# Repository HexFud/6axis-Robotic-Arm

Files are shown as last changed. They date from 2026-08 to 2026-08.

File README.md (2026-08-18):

## 6 Axis Robotic Arm

I created this 6 axis robotic arm entirely from scratch starting from the PCB to the 3D modelling and designing.

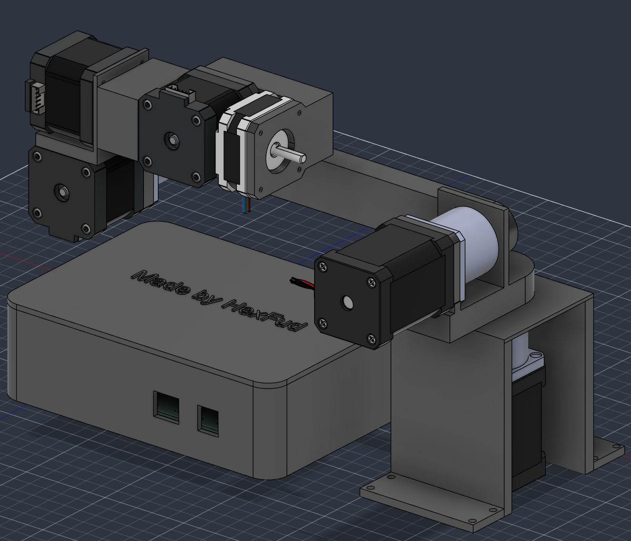
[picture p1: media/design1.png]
design1


## How this was made

I designed the PCB that can take up to 6 motors (I used 6 NEMA 17) with 6 driver boards that you can directly plug into the PCB. In the PCB case there is a cutout for a 40mm fan directly pluggable into the dedicated +5V socket (identified by FAN or J8 connector), this is foundamental to keep the motor drivers cool and keep things as safe as possible. The board runs on 24V connection and includes connections for:

1. **6 limit switches** for homing each joint
2. **A CAN Bus interface**
3. **An emergency stop button socket** for safety reason. 

## External connections breakdown

1. **E-STOP (J21)** The emergency stop circuit is NC so the board without this button won't power on, if you want to avoid this you can short 2 pins of the J21 connector with a jumper (please mind your safety)
2. **CAN Bus (J22)** This is the port to make the PCB comunicate with the PC and it only has 2 pins CAN_H and CAN_L if you want to send commands directly to the board you need to have a USB-CAN adapter
3. **Power button (J19)** The socket on the PCB has 4 pins
 
| Pin | Function | Where to connect |
| :---: | :--- | :--- |
| **1** | `GND` | Switch contact + LED Negative (`-`) wire |
| **2** | `PWR` | Switch contact |
| **3** | `+3V3` | LED Positive (`+`) wire |
| **4** | `Reserved` | *Do not connect any wire to it* |

## Mechanical design and why I chose certain components

To make sure the arm can lift certain payloads wihout struggling I preferred to not use a direct-drive style to move the joints, this is why for the most heavy and tourqe demanding parts I paired the NEMA 17 motors with 20:1 and 10:1 gearboxes (you can see them marked in red)

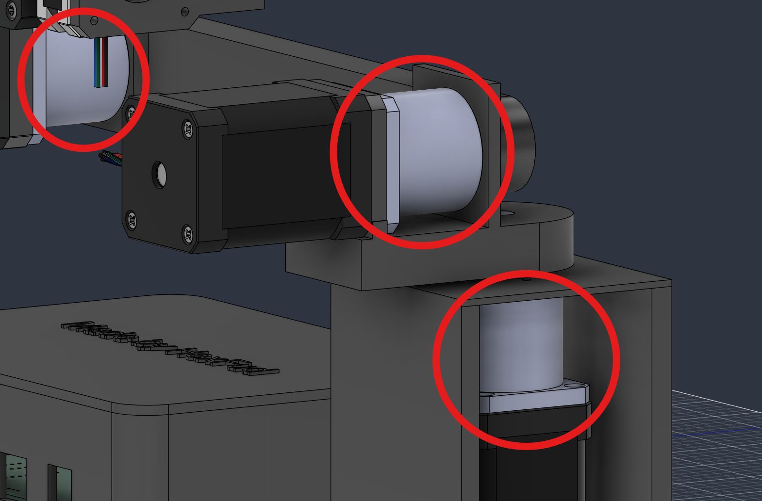
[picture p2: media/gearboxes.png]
gearboxes


## How to flash the firmware

My project doesn't have a USB-C or other type of interfaces so to flash the firmware you need a ST-LINK V2 where you need to wire up the correct cable from the usb to the board (J18 connector) and download the free software [STM32CubeProgrammer](https://www.st.com/content/st_com/en/stm32cubeprogrammer.html) and you simply need to upload the firmware.

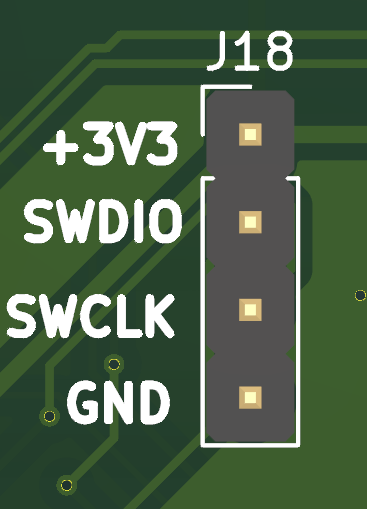
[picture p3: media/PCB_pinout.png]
Connector pinout


Steps to reproduce (note that you need to do both):

In Arduino IDE:
1. Install Arduino IDE
2. Paste https://github.com/stm32duino/BoardManagerFiles/raw/main/package_stmicroelectronics_index.json into prefernces -> additional board manager URL's
3. Search STM32 into the boards stab and install it
4. Go in tools -> board -> STM32 MCU based boards and select Generic STM32F4 series
5. Go in tools -> board part number and select Generic F446RETx
6. Go to sketch -> export compiled binary

In STM32CubeProgrammer:
1. Install the software from the link above
2. Insert the ST-Link V2 USB into the pc
3. Connect the pins explained above (do not connect the 24V power supply, the ST-Link has enough power to power the chip to flash)
4. In STM32CubeProgrammer ensure that ST-LINK is selected and click connect
5. Go in the erasing & programming tab and select the previously exported .bin file
6. Click start programming and if everything went right you'll see Download verified successfully

## Filament reccomendation

Because stepper motors and the drivers generate heat around 50°C-60°C I strongly reccomend to use filaments like PETG, ABS or ASA instead of standard PLA ensuring the plastic won't soften, warp or melt during intensive load.

## ⚠️⚠️ Safety advice ⚠️⚠️

This project includes experimental software, hardware designs, and assembly documentation are still under development and may contain bugs, errors, or incomplete features. By using, building, or modifying this project, you acknowledge that:

1. You use this project entirely at your own risk
2. You are solely responsible for safe assembly, testing, and operation
3. The autor isn't responsible for any type of damage, injury or loss to people or the machine itself

By proceeding, you accept all risks and agree to these conditions. If you do not acknowledge these risks and conditions, please do not use or build this project.

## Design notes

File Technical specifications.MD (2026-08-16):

# Technical Specifications

## 1. Power Supply

| Parameter | Value |
|---|---|
| DC input voltage | 18-28V, 24V DC nominal |
| Standby power consumption (motors energized, holding torque) | 10-15W |
| Standard multi-axis operation power consumption | 100-150W (average) |
| Peak power (simultaneous high-speed acceleration) | ~240W |

## 2. Current Ratings

| Rail / component | Value |
|---|---|
| Main 24V distribution, system peak | up to 8A |
| Each TMC5160 driver, continuous RMS current | 1.8-2.5A per axis |
| Each TMC5160 driver, transient peak burst (with active forced-air cooling) | up to 3.6A |
| 3.3V logic rail, continuous consumption (180MHz core clock) | ~150mA |
| Dedicated 5V rail (cooling fan + auxiliary peripherals) | up to 500mA |

## 3. Thermal Limits

| Parameter | Value |
|---|---|
| Driver silicon pre-warning threshold | 100°C |
| Automatic over-temperature shutdown | 120°C |
| Operating ambient temperature range | 0-45°C |

## 4. Mechanical and Performance

| Parameter | Value |
|---|---|
| Reduction ratio on primary joints | 20:1 |
| Maximum torque (base and shoulder axes) | > 12.8 Nm |
| Maximum recommended payload (at 400mm reach) | 1.5-2.0 kg |
| Maximum joint angular velocity | ~180°/s (30 RPM at gearbox output) |
| Maximum tool tip linear speed | up to 600 mm/s |
| Minimum angular resolution | 0.0056° per microstep |
| Estimated positioning repeatability | 0.1-0.2 mm |

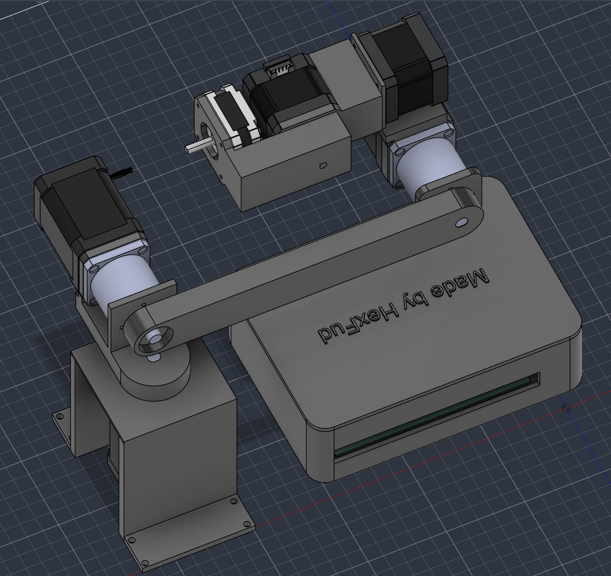
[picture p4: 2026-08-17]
media/design2.png

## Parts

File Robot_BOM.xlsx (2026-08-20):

Reference | Qty | Part | Prezzo unit. (€) | Totale (€) | Link AliExpress | Totale $
U9 | 1 | STM32F446RET6 | €5.00 | €5.00 | https://www.aliexpress.com/item/1005009080237227.html | 5.85
U8 | 1 | AMS1117-3.3 (10pz) | €1.75 | €1.75 | https://www.aliexpress.com/item/33022785837.html | 2.0475
U10 | 1 | SN65HVD230 | €3.80 | €3.80 | https://it.aliexpress.com/item/1005006203720105.html | 4.446
U11 | 1 | PC817 (20pz) | €1.20 | €1.20 | https://www.aliexpress.com/item/1005009954843288.html | 1.404
Q10 | 1 | AO4407A (10pz) | €5.84 | €5.84 | https://www.aliexpress.com/item/1005006303212098.html | 6.8328
D2 | 1 | SMBJ36A (50pz) | €3.50 | €3.50 | https://www.aliexpress.com/item/1005002204221759.html | 4.095
F3 | 1 | PTC 1812 3A 36V (100pz) | €6.70 | €6.70 | https://www.aliexpress.com/item/32834981808.html | 7.839
Y3 | 1 | 8MHz 5032 (10pz) | €2.00 | €2.00 | https://www.aliexpress.com/item/1005008632259152.html | 2.34
J24, J26… | 2 | Header 2x8 F (10pz) | €2.90 | €5.80 | https://www.aliexpress.com/item/32847429443.html | 6.786
J25, J27… | 6 | JST-XH-4P (kit) | €20.19 | €20.19 | https://it.aliexpress.com/item/1005009894347474.html | 23.6223
J2, J8…J12, J20 | 7 | JST-XH-3P (kit) |  |  |  | 0
J21, J22 | 2 | JST-XH-2P (kit) |  |  |  | 0
J19 | 1 | JST-PH-4P (kit) | €9.18 | €9.18 | https://www.aliexpress.com/item/1005010504121398.html | 10.7406
J17 | 1 | 2 pin screw terminals 5mm (100pz) | €10.42 | €10.42 | https://www.aliexpress.com/item/1005011820630047.html | 12.1914
J18 | 1 | Header 4 pins (20pz) | €2.05 | €2.05 | https://www.aliexpress.com/item/1005007093958549.html | 2.3985
C18, C20… | 6 | 100µF 35V (40pz) | €2.00 | €2.00 | https://it.aliexpress.com/item/1005011811368397.html | 2.34
C15, C16 | 2 | 10µF 0805 (smd) | €2.00 | €2.00 | https://it.aliexpress.com/item/1005012364450156.html | 2.34
C12 | 1 | 4.7µF 0805 (smd) | €2.00 | €2.00 |  | 2.34
C6..C14, C17… | 14 | 100nF 50V 0805 (smd) | €4.50 | €4.50 | https://it.aliexpress.com/item/1005010243722146.html | 5.265
C1, C2 | 2 | 18pF 50V 0805 (smd) | €5.00 | €5.00 |  | 5.85
R4, R8, R9..R21 | 12 | 10k 0805 (book) | €40.00 | €40.00 | https://it.aliexpress.com/item/1005005504891922.html | 46.8
R7, R10 | 2 | 100k 0805 (book) |  |  |  | 0
R18 | 1 | 2.2k 0805 (book) |  |  |  | 0
R5, R6 | 2 | 1k 0805 (book) |  |  |  | 0
R20 | 1 | 120R 0805 (book) |  |  |  | 0
D4, D5 | 2 | LED 0805 (100pz) BUY RED AND BLUE !!! | €1.00 | €2.00 | https://it.aliexpress.com/item/1005012857004893.html | 2.34
SW2 | 1 | Tactile 6x6 (50pz) | €2.91 | €2.91 | https://it.aliexpress.com/item/32815937778.html | 3.4047
M1, M2 | 2 | NEMA 17 60mm | €18.00 | €36.00 | https://it.aliexpress.com/item/1005008385016960.html | 42.12
M3, M4, M5 | 3 | NEMA 17 40mm | €9.00 | €27.00 | https://it.aliexpress.com/item/1005008459399126.html | 31.59
M6 | 1 | NEMA 17 20mm | €12.00 | €12.00 | https://it.aliexpress.com/item/1005010167230439.html | 14.04
DRV1..DRV6 | 6 | TMC2130 SPI | €7.30 | €44.00 | https://it.aliexpress.com/item/1005004590796152.html | 51.48
PSU1 | 1 | MeanWell LRS-200-24 | €21.00 | €21.00 | https://it.aliexpress.com/item/1005006917685323.html | 24.57
FAN1 | 1 | Noctua NF-A4x20 5V | €40.00 | €40.00 | https://www.aliexpress.com/item/1005001936967690.html | 46.8
ESTOP1 | 1 | E-STOP 22mm NC | €5.00 | €5.00 | https://it.aliexpress.com/item/1005008518428843.html | 5.85
BTN1 | 1 | 12mm LED button 6V | €2.00 | €2.00 | https://it.aliexpress.com/item/1005007274034264.html | 2.34
PRG1 | 1 | ST-Link V2 | €2.50 | €2.50 | https://it.aliexpress.com/item/1005009955503752.html | 2.925
 | 2 | Nema 17 20:1 gearbox | €20.00 | €40.00 | https://it.aliexpress.com/item/1005010354201440.html | 46.8
 | 1 | Nema 17 10:1 gearbox | €18.00 | €18.00 |  | 21.06
 | 2 | 1kg PETG | €25.00 | €50.00 |  | 58.5
 | 1 | PCB board | €100.00 | €100.00 |  | 117
TOTALE | 97 |  |  | €523.59 |  | $612.60

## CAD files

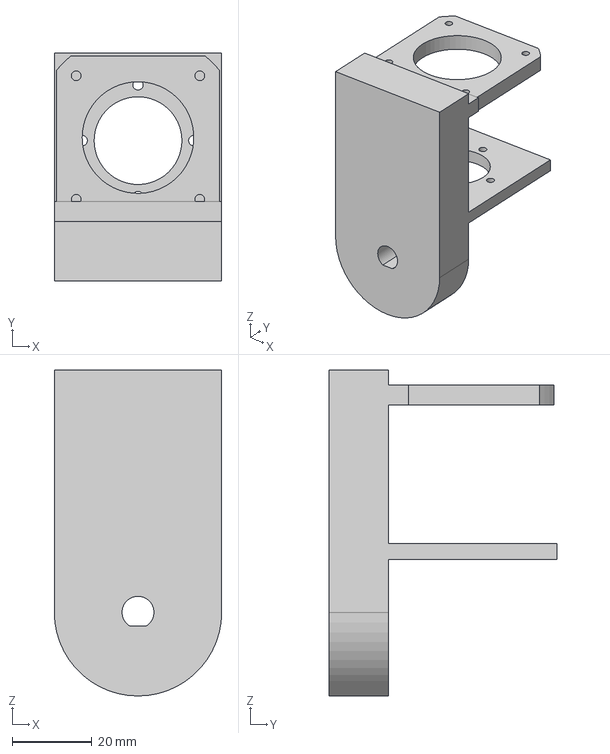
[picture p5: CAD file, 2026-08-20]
production/Arm_1.step
42.0 x 57.2 x 81.8 mm

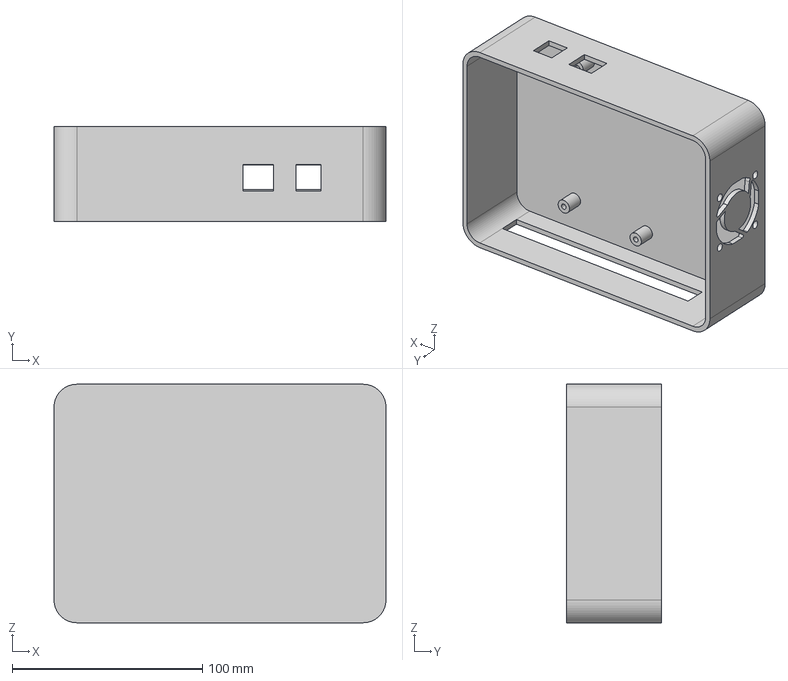
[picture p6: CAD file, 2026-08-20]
production/Arm_Case.step
174.4 x 50.0 x 125.3 mm

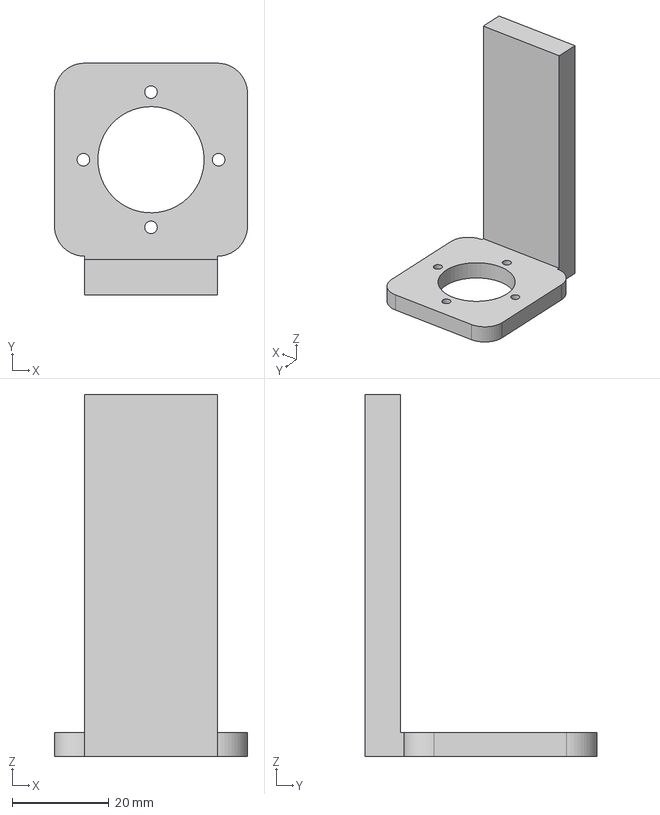
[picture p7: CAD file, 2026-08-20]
production/Arm_3.step
40.0 x 48.0 x 75.0 mm

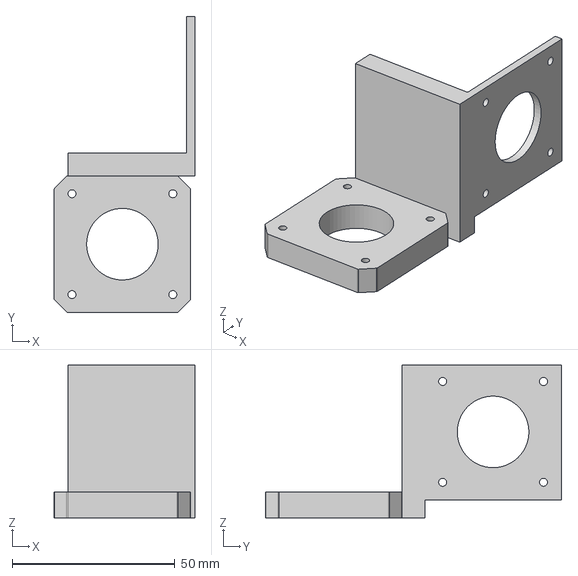
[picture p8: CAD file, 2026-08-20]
production/Arm_4.step
43.3 x 91.0 x 47.0 mm

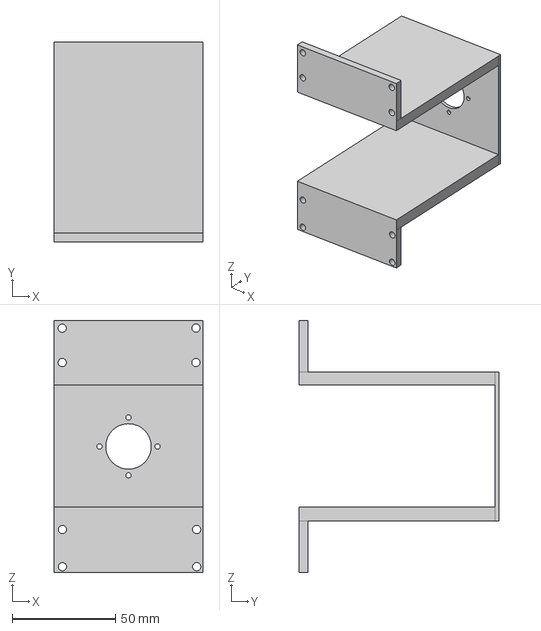
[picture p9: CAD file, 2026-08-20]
production/Arm_Base.step
72.0 x 97.0 x 122.0 mm

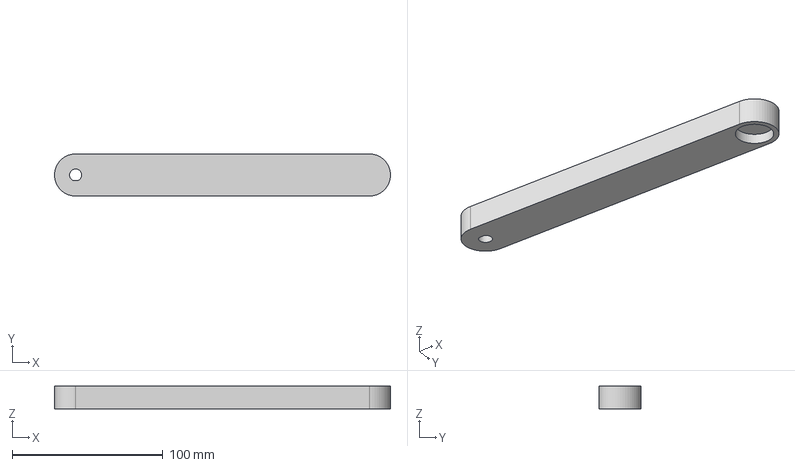
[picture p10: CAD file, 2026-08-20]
production/Arm_2.step
223.0 x 28.0 x 15.0 mm

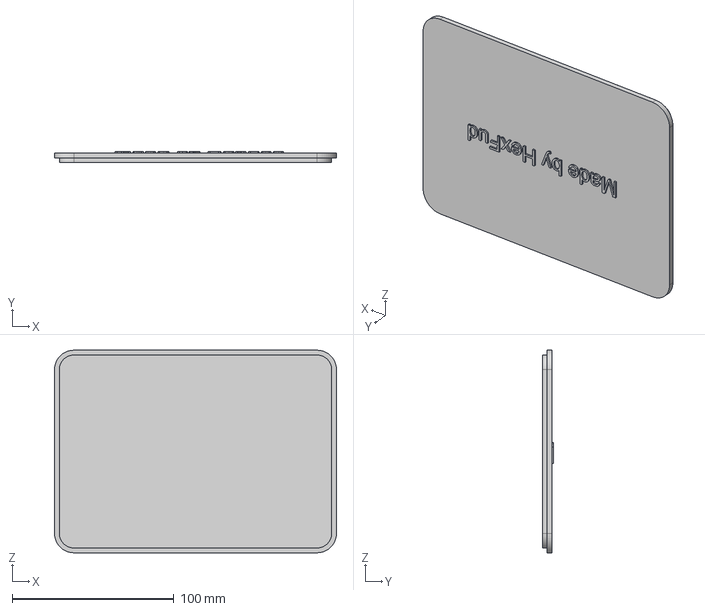
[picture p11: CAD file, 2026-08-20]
production/Case_lid.step
174.4 x 7.00 x 125.3 mm

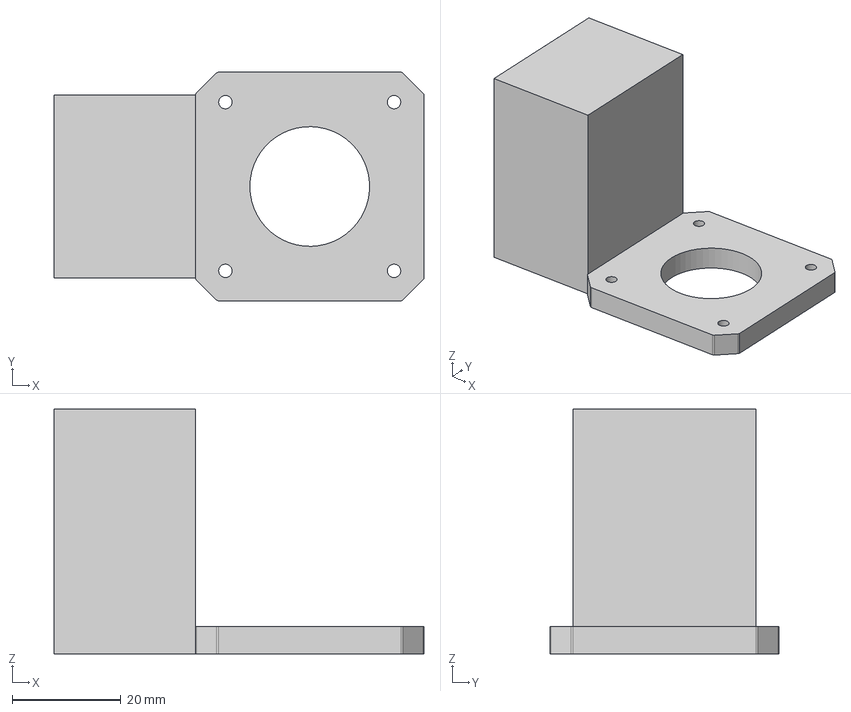
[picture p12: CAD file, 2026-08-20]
production/Arm_5.step
68.0 x 42.0 x 45.0 mm

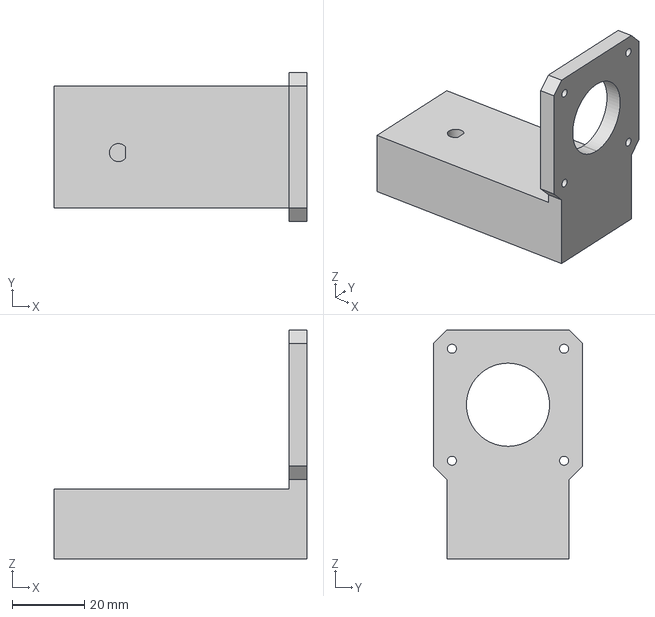
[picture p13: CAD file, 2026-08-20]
production/Arm_6.step
70.0 x 41.3 x 63.3 mm

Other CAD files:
CAD/Complete_arm.stl

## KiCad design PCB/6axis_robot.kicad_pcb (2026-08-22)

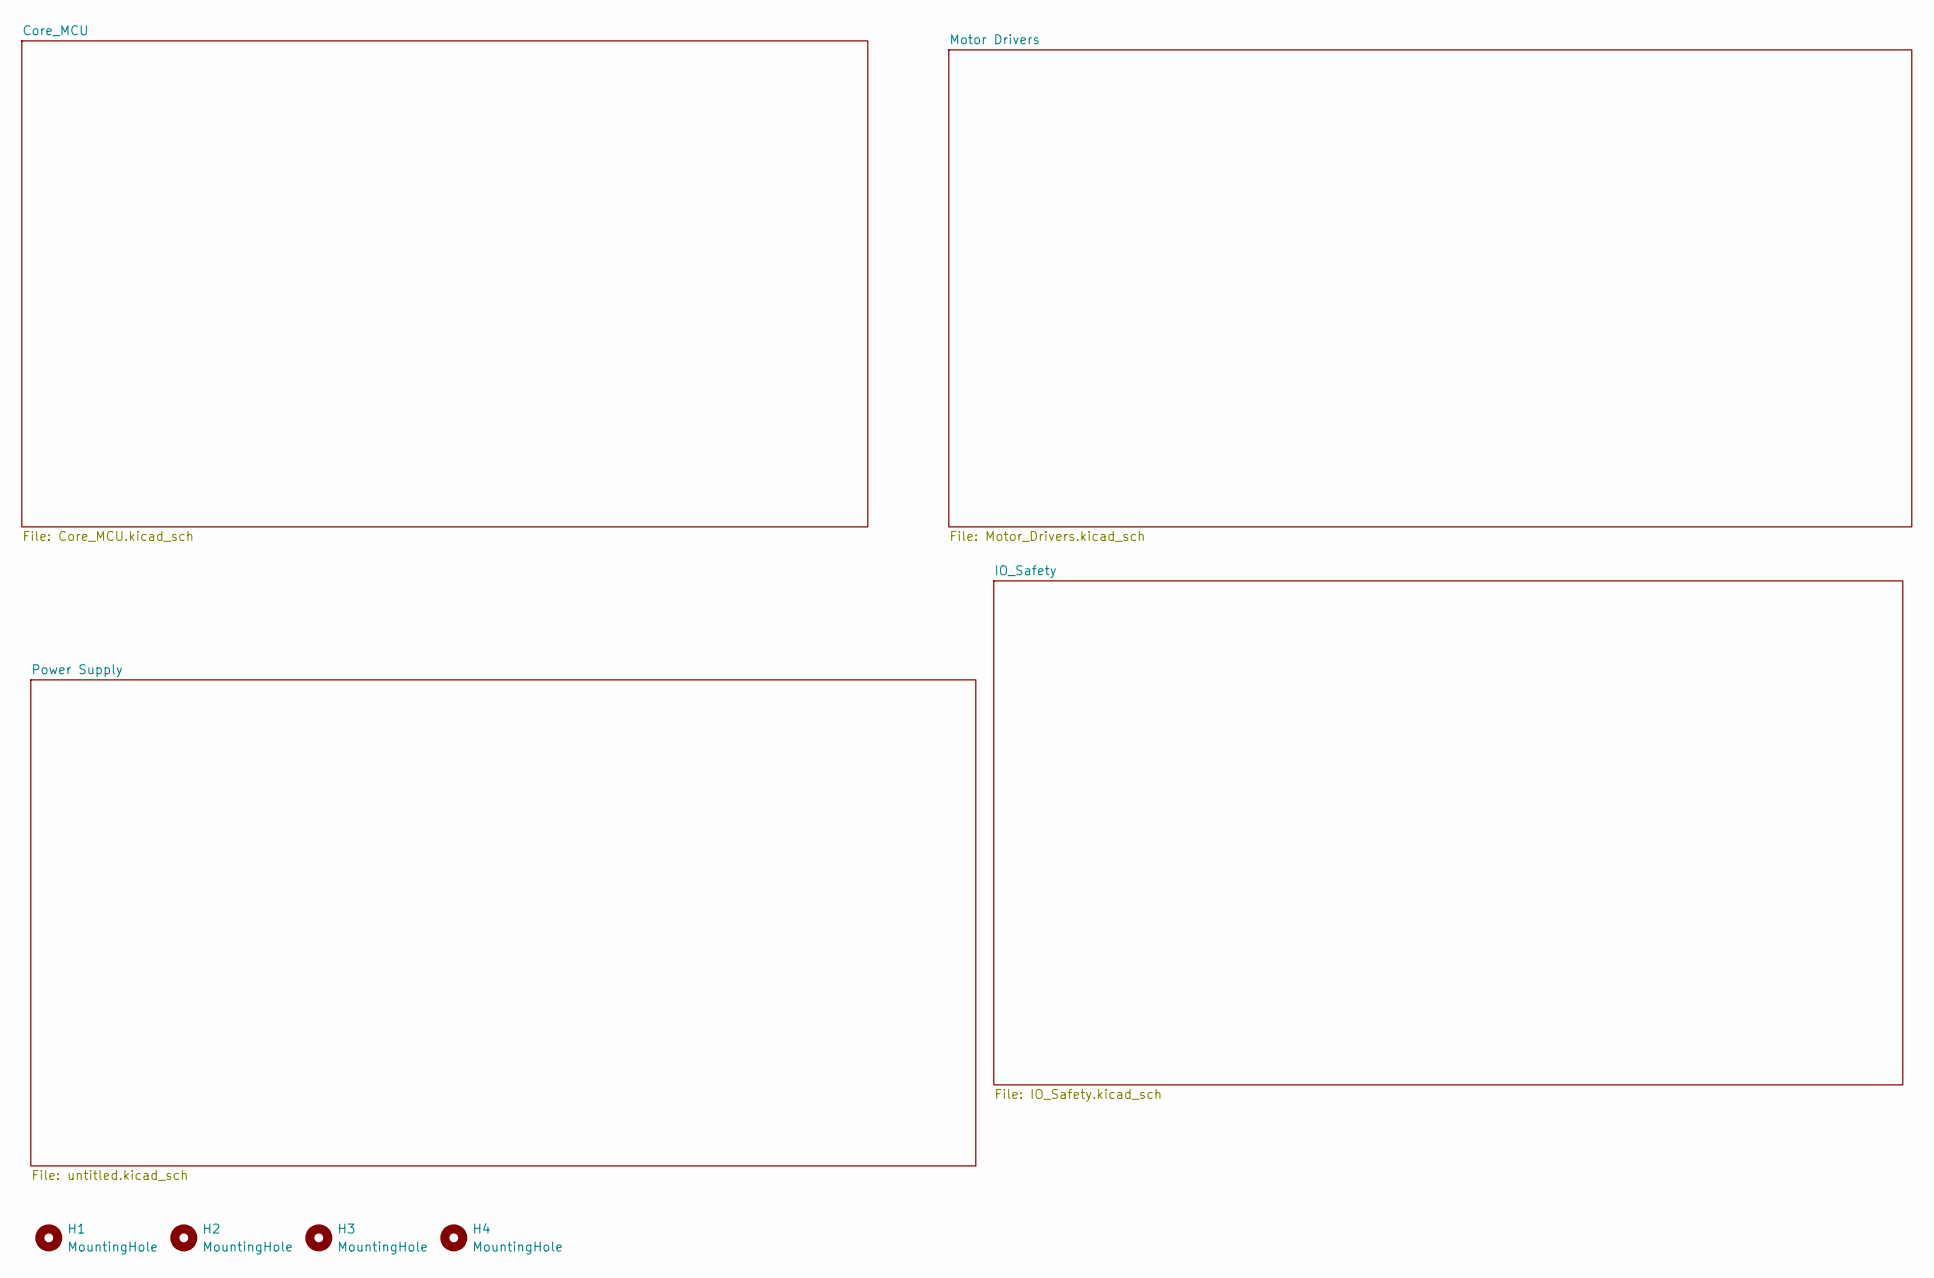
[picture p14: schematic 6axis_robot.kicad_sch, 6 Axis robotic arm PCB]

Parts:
H1, H2, H3, H4: MountingHole; MountingHole_3.2mm_M3

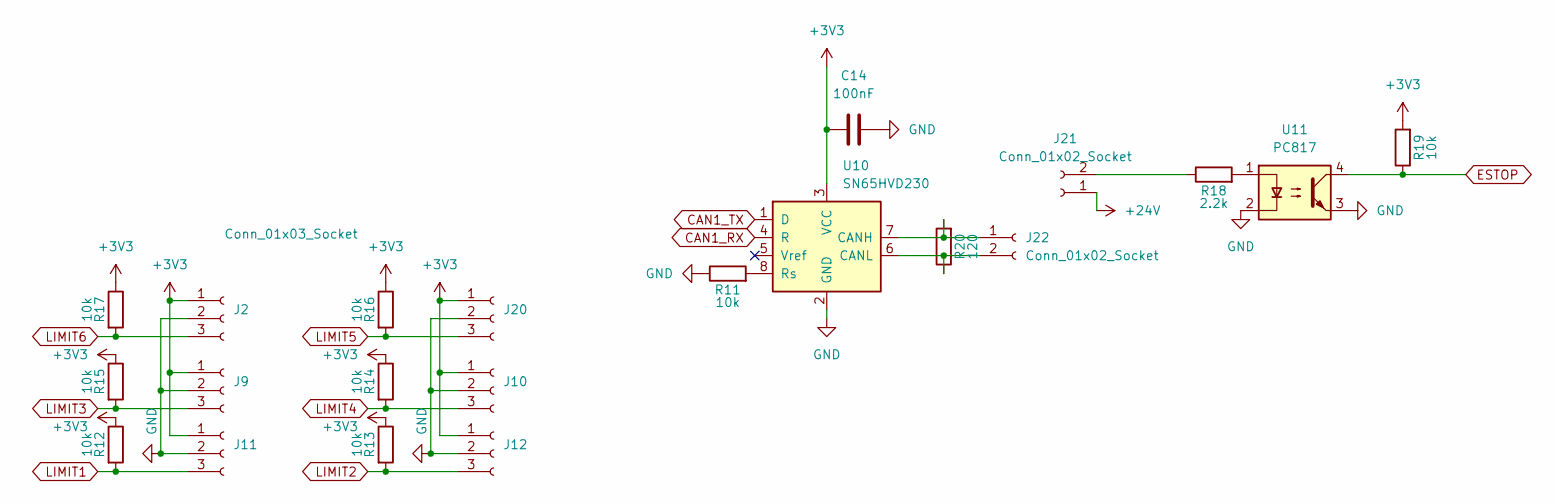
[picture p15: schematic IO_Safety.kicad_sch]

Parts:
C14: 100nF; C_0805_2012Metric
J2, J9, J10, J11, J12, J20: Conn_01x03_Socket; JST_XH_B3B-XH-A_1x03_P2.50mm_Vertical
J21, J22: Conn_01x02_Socket; JST_XH_B2B-XH-A_1x02_P2.50mm_Vertical
R11, R12, R13, R14, R15, R16, R17, R19: 10k; R_0805_2012Metric
R18: 2.2k; R_0805_2012Metric
R20: 120; R_0805_2012Metric
U10: SN65HVD230; SOIC-8_3.9x4.9mm_P1.27mm
U11: PC817; DIP-4_W7.62mm

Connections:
+3V3: C14.1, J2.1, J9.1, J10.1, J11.1, J12.1, J20.1, R12.1, R13.1, R14.1, R15.1, R16.1, R17.1, R19.2, U10.3 (VCC); also elsewhere on the board
+24V: J21.1; also elsewhere on the board
CAN1_RX: U10.4 (R); also elsewhere on the board
CAN1_TX: U10.1 (D); also elsewhere on the board
ESTOP: R19.1, U11.4; also elsewhere on the board
GND: C14.2, J2.2, J9.2, J10.2, J11.2, J12.2, J20.2, R11.1, U10.2 (GND), U11.2, U11.3; also elsewhere on the board
LIMIT1: J11.3, R12.2; also elsewhere on the board
LIMIT2: J12.3, R13.2; also elsewhere on the board
LIMIT3: J9.3, R15.2; also elsewhere on the board
LIMIT4: J10.3, R14.2; also elsewhere on the board
LIMIT5: J20.3, R16.2; also elsewhere on the board
LIMIT6: J2.3, R17.2; also elsewhere on the board
unnamed: J21.2, R18.1
unnamed: J22.1, R20.2, U10.7 (CANH)
unnamed: J22.2, R20.1, U10.6 (CANL)
unnamed: R18.2, U11.1
unnamed: R11.2, U10.8 (Rs)

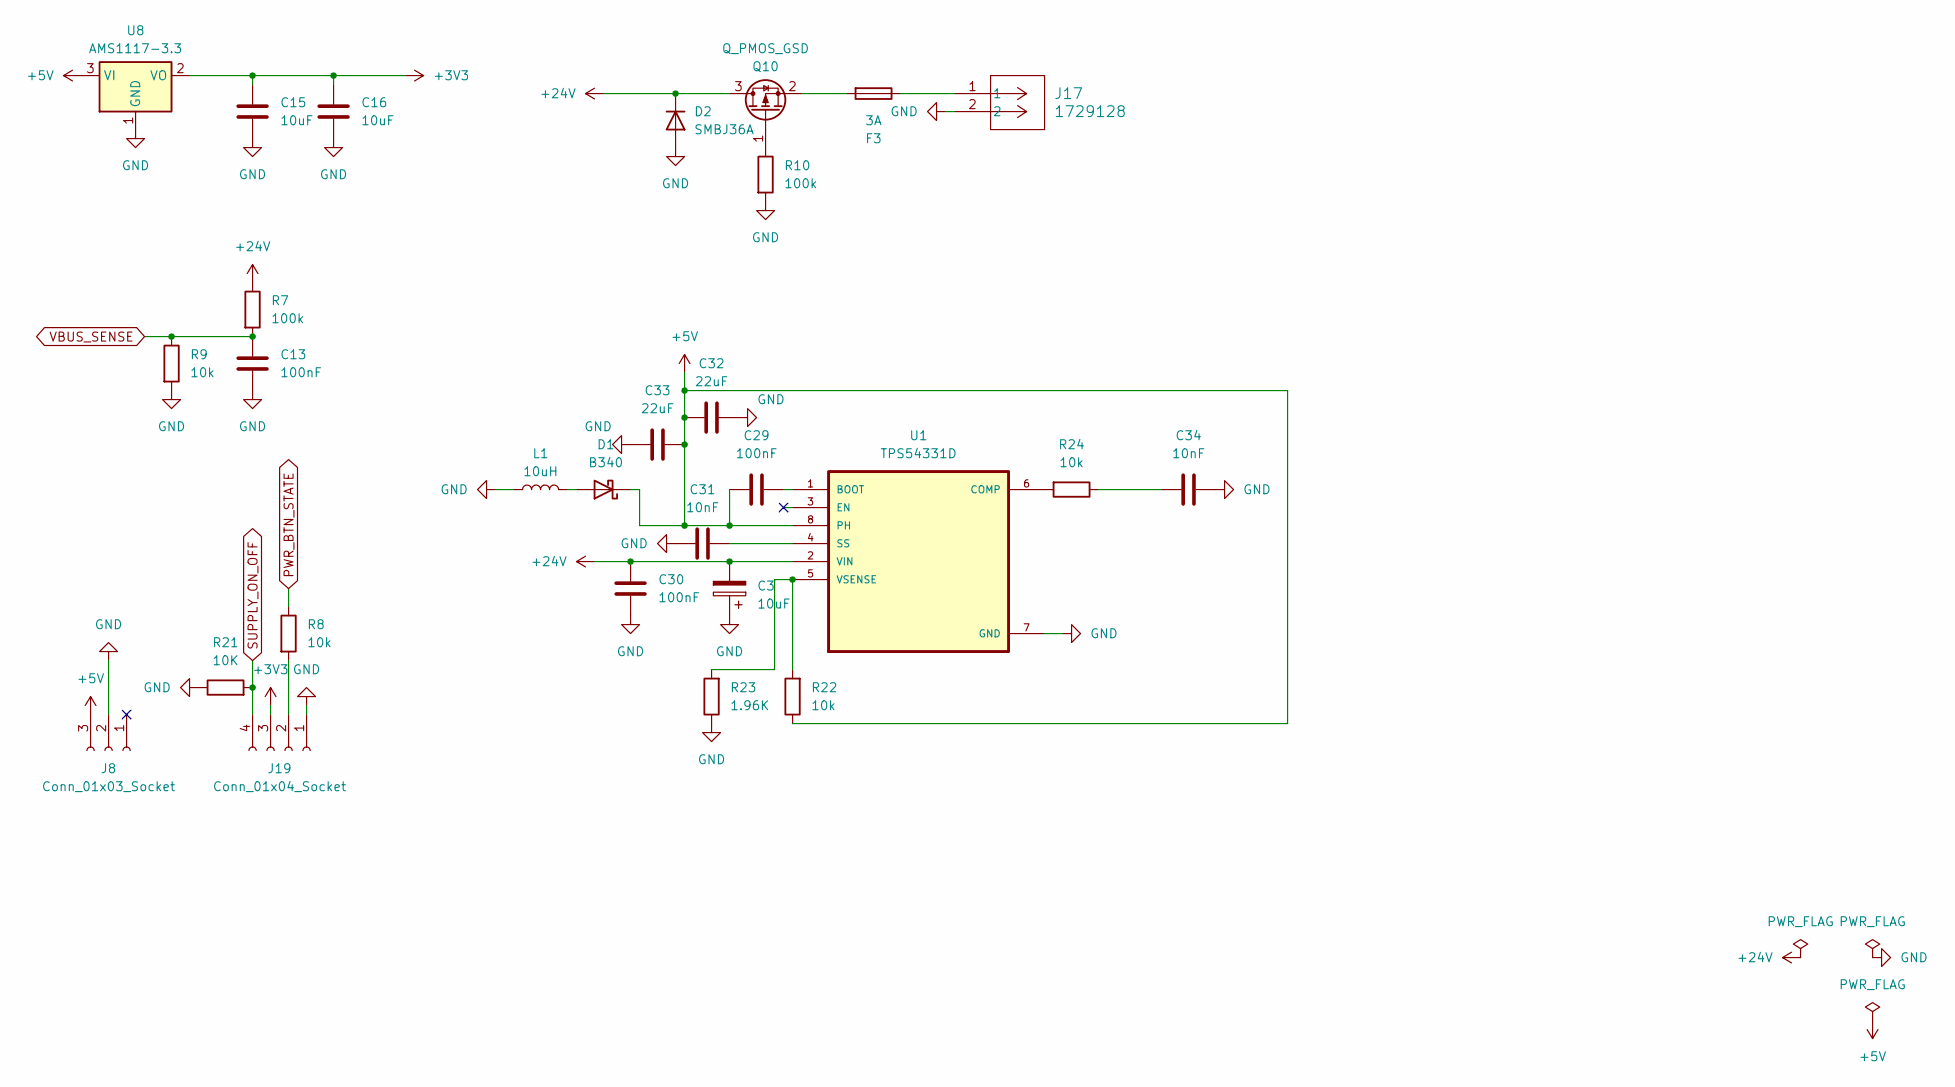
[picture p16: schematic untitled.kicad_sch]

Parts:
C3: 10uF; CP_Radial_D6.3mm_P2.50mm
C13, C29, C30: 100nF; C_0805_2012Metric
C15, C16: 10uF; C_0805_2012Metric
C31, C34: 10nF; C_0805_2012Metric
C32, C33: 22uF; C_0805_2012Metric
D1: B340; D_SMC
D2: SMBJ36A; D_SMB
F3: 3A; Fuse_1812_4532Metric
J8: Conn_01x03_Socket; JST_XH_B3B-XH-A_1x03_P2.50mm_Vertical
J17: 1729128; CONN_1729128_PXC
J19: Conn_01x04_Socket; JST_PH_B4B-PH-K_1x04_P2.00mm_Vertical
L1: 10uH; L_Sunlord_SWPA6045S
Q10: Q_PMOS_GSD; SOT-23
R7, R10: 100k; R_0805_2012Metric
R8, R9, R22, R24: 10k; R_0805_2012Metric
R21: 10K; R_0805_2012Metric
R23: 1.96K; R_0805_2012Metric
U1: TPS54331D; SOIC127P599X175-8N
U8: AMS1117-3.3; SOT-223-3_TabPin2

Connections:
+3V3: C15.2, C16.2, J19.3, U8.2 (VO); also elsewhere on the board
+5V: C29.1, C32.1, C33.2, D1.1 (K), J8.3, R22.1, U1.8 (PH), U8.3 (VI)
+24V: C3.2, C30.1, D2.1 (K), Q10.3 (D), R7.1, U1.2 (VIN); also elsewhere on the board
GND: C3.1, C13.2, C15.1, C16.1, C30.2, C31.1, C32.2, C33.1, C34.2, D2.2 (A), J8.2, J17.2, J19.1, L1.1, R9.2, R10.2, R21.1, R23.1, U1.7 (GND), U8.1 (GND); also elsewhere on the board
unnamed: C34.1, R24.1
unnamed: D1.2 (A), L1.2
unnamed: F3.1, J17.1
unnamed: J19.2, R8.2
unnamed: Q10.1 (G), R10.1
unnamed: F3.2, Q10.2 (S)
unnamed: C29.2, U1.1 (BOOT)
unnamed: R24.2, U1.6 (COMP)
unnamed: C31.2, U1.4 (SS)
unnamed: R22.2, R23.2, U1.5 (VSENSE)
PWR_BTN_STATE: R8.1; also elsewhere on the board
SUPPLY_ON_OFF: J19.4, R21.2; also elsewhere on the board
VBUS_SENSE: C13.1, R7.2, R9.1; also elsewhere on the board

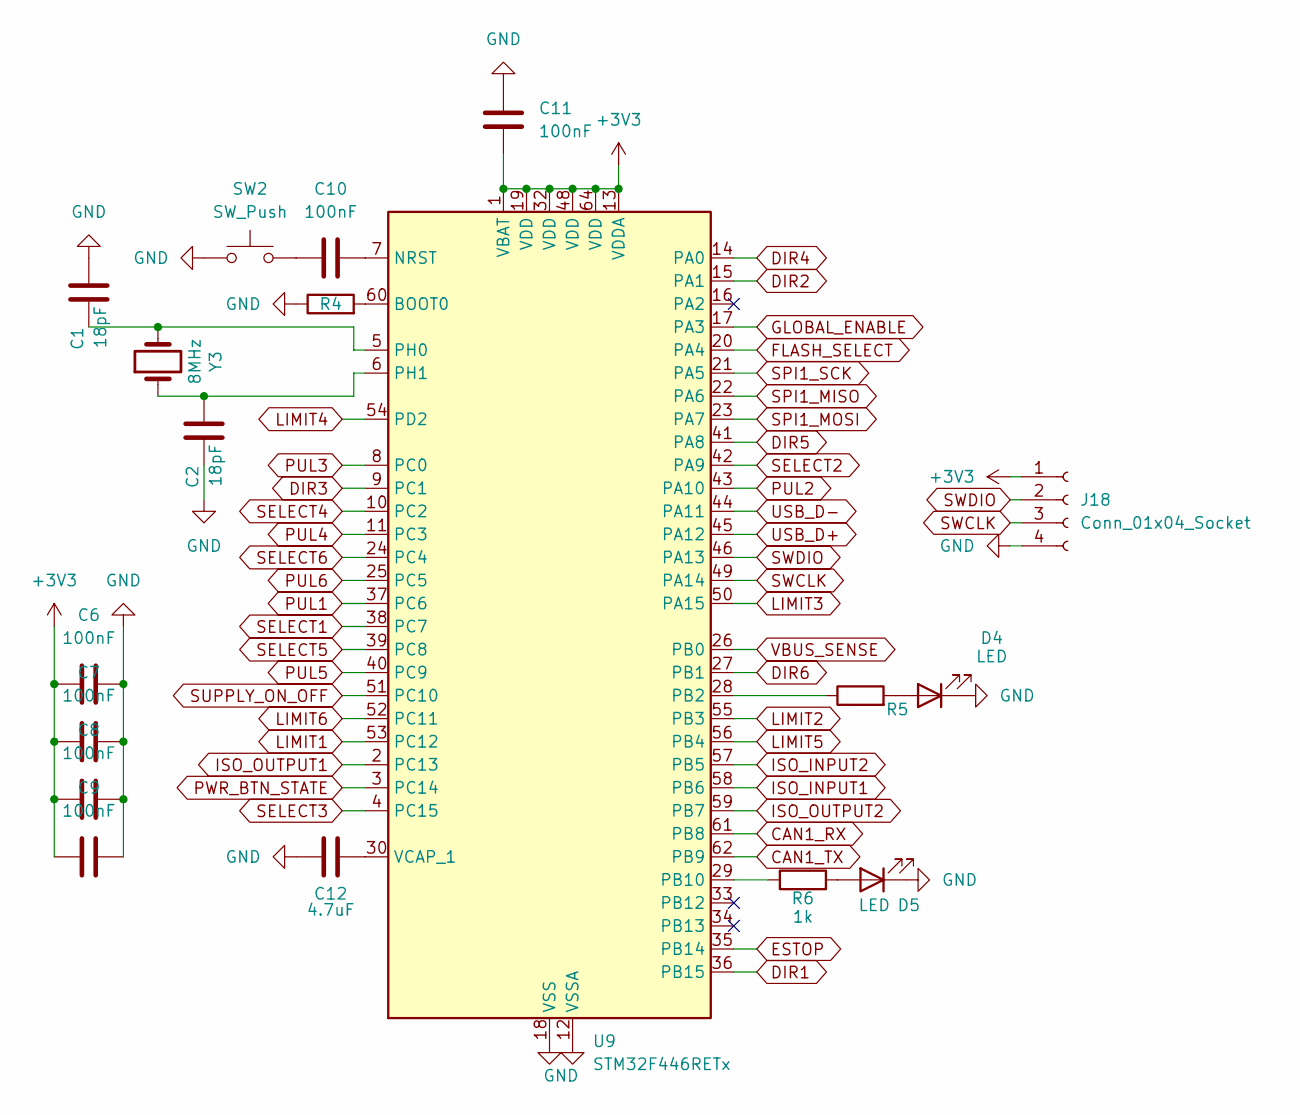
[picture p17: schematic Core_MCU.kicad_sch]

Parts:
C1, C2: 18pF; C_0805_2012Metric
C6, C7, C8, C9, C10, C11: 100nF; C_0805_2012Metric
C12: 4.7uF; C_0805_2012Metric
D4, D5: LED; LED_0805_2012Metric
J18: Conn_01x04_Socket; PinHeader_1x04_P2.54mm_Vertical
R4: 10k; R_0805_2012Metric
R5, R6: 1k; R_0805_2012Metric
SW2: SW_Push; SW_PUSH_6mm
U9: STM32F446RETx; LQFP-64_10x10mm_P0.5mm
Y3: 8MHz; Crystal_SMD_5032-2Pin_5.0x3.2mm

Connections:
+3V3: C6.2, C7.2, C8.2, C9.2, C11.2, J18.1, U9.1 (VBAT), U9.13 (VDDA), U9.19 (VDD), U9.32 (VDD), U9.48 (VDD), U9.64 (VDD); also elsewhere on the board
CAN1_RX: U9.61 (PB8); also elsewhere on the board
CAN1_TX: U9.62 (PB9); also elsewhere on the board
DIR1: U9.36 (PB15); also elsewhere on the board
DIR2: U9.15 (PA1); also elsewhere on the board
DIR3: U9.9 (PC1); also elsewhere on the board
DIR4: U9.14 (PA0); also elsewhere on the board
DIR5: U9.41 (PA8); also elsewhere on the board
DIR6: U9.27 (PB1); also elsewhere on the board
ESTOP: U9.35 (PB14); also elsewhere on the board
FLASH_SELECT: U9.20 (PA4)
GLOBAL_ENABLE: U9.17 (PA3); also elsewhere on the board
GND: C1.2, C2.1, C6.1, C7.1, C8.1, C9.1, C11.1, C12.1, D4.1 (K), D5.1 (K), J18.4, R4.1, SW2.1, U9.12 (VSSA), U9.18 (VSS), U9.31 (VSS), U9.47 (VSS), U9.63 (VSS); also elsewhere on the board
ISO_INPUT1: U9.58 (PB6)
ISO_INPUT2: U9.57 (PB5)
ISO_OUTPUT1: U9.2 (PC13)
ISO_OUTPUT2: U9.59 (PB7)
LIMIT1: U9.53 (PC12); also elsewhere on the board
LIMIT2: U9.55 (PB3); also elsewhere on the board
LIMIT3: U9.50 (PA15); also elsewhere on the board
LIMIT4: U9.54 (PD2); also elsewhere on the board
LIMIT5: U9.56 (PB4); also elsewhere on the board
LIMIT6: U9.52 (PC11); also elsewhere on the board
unnamed: C10.2, SW2.2
unnamed: D4.2 (A), R5.2
unnamed: D5.2 (A), R6.2
unnamed: R4.2, U9.60 (BOOT0)
unnamed: C10.1, U9.7 (NRST)
unnamed: R5.1, U9.28 (PB2)
unnamed: R6.1, U9.29 (PB10)
unnamed: C1.1, U9.5 (PH0), Y3.2
unnamed: C2.2, U9.6 (PH1), Y3.1
unnamed: C12.2, U9.30 (VCAP_1)
PUL1: U9.37 (PC6); also elsewhere on the board
PUL2: U9.43 (PA10); also elsewhere on the board
PUL3: U9.8 (PC0); also elsewhere on the board
PUL4: U9.11 (PC3); also elsewhere on the board
PUL5: U9.40 (PC9); also elsewhere on the board
PUL6: U9.25 (PC5); also elsewhere on the board
PWR_BTN_STATE: U9.3 (PC14); also elsewhere on the board
SELECT1: U9.38 (PC7); also elsewhere on the board
SELECT2: U9.42 (PA9); also elsewhere on the board
SELECT3: U9.4 (PC15); also elsewhere on the board
SELECT4: U9.10 (PC2); also elsewhere on the board
SELECT5: U9.39 (PC8); also elsewhere on the board
SELECT6: U9.24 (PC4); also elsewhere on the board
SPI1_MISO: U9.22 (PA6); also elsewhere on the board
SPI1_MOSI: U9.23 (PA7); also elsewhere on the board
SPI1_SCK: U9.21 (PA5); also elsewhere on the board
SUPPLY_ON_OFF: U9.51 (PC10); also elsewhere on the board
SWCLK: J18.3, U9.49 (PA14)
SWDIO: J18.2, U9.46 (PA13)
USB_D+: U9.45 (PA12)
USB_D-: U9.44 (PA11)
VBUS_SENSE: U9.26 (PB0); also elsewhere on the board

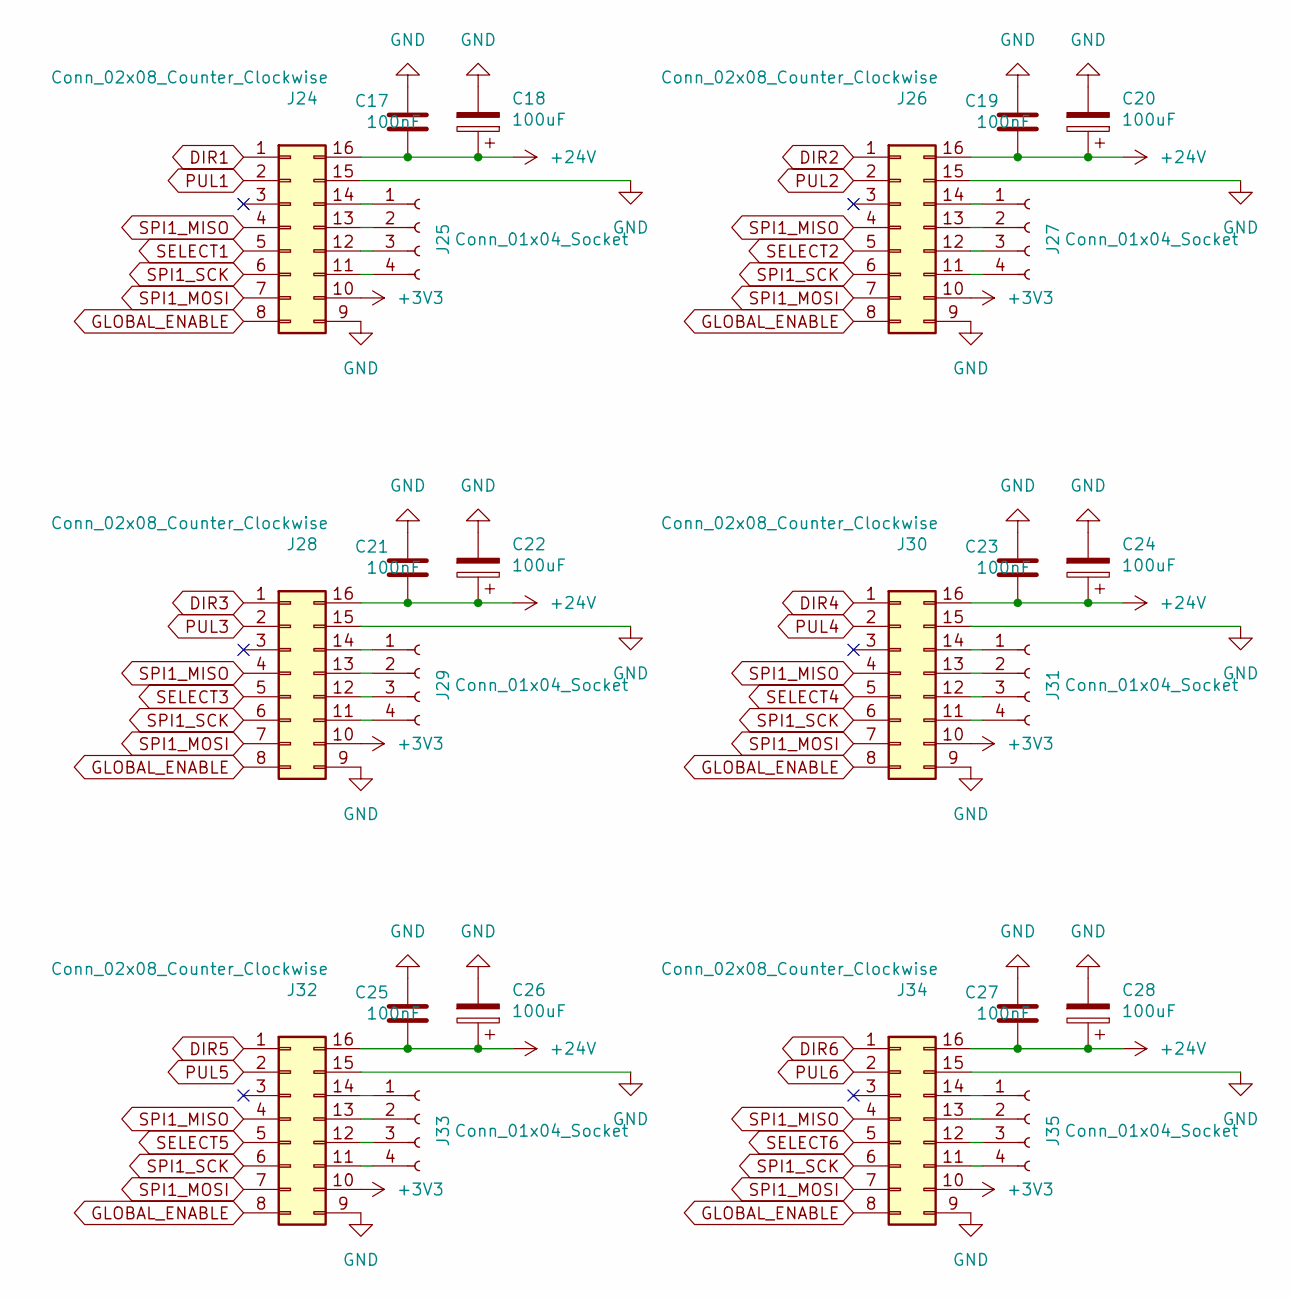
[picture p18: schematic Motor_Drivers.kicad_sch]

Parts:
C17, C19, C21, C23, C25, C27: 100nF; C_0805_2012Metric
C18, C20, C22, C24, C26, C28: 100uF; CP_Radial_D6.3mm_P2.50mm
J24, J26, J28, J30, J32, J34: Conn_02x08_Counter_Clockwise; 8825
J25, J27, J29, J31, J33, J35: Conn_01x04_Socket; JST_XH_B4B-XH-A_1x04_P2.50mm_Vertical

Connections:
+3V3: J24.10, J26.10, J28.10, J30.10, J32.10, J34.10; also elsewhere on the board
+24V: C17.2, C18.1, C19.2, C20.1, C21.2, C22.1, C23.2, C24.1, C25.2, C26.1, C27.2, C28.1, J24.16, J26.16, J28.16, J30.16, J32.16, J34.16; also elsewhere on the board
DIR1: J24.1; also elsewhere on the board
DIR2: J26.1; also elsewhere on the board
DIR3: J28.1; also elsewhere on the board
DIR4: J30.1; also elsewhere on the board
DIR5: J32.1; also elsewhere on the board
DIR6: J34.1; also elsewhere on the board
GLOBAL_ENABLE: J24.8, J26.8, J28.8, J30.8, J32.8, J34.8; also elsewhere on the board
GND: C17.1, C18.2, C19.1, C20.2, C21.1, C22.2, C23.1, C24.2, C25.1, C26.2, C27.1, C28.2, J24.9, J24.15, J26.9, J26.15, J28.9, J28.15, J30.9, J30.15, J32.9, J32.15, J34.9, J34.15; also elsewhere on the board
unnamed: J24.11, J25.4
unnamed: J24.12, J25.3
unnamed: J24.13, J25.2
unnamed: J24.14, J25.1
unnamed: J26.11, J27.4
unnamed: J26.12, J27.3
unnamed: J26.13, J27.2
unnamed: J26.14, J27.1
unnamed: J28.11, J29.4
unnamed: J28.12, J29.3
unnamed: J28.13, J29.2
unnamed: J28.14, J29.1
unnamed: J30.11, J31.4
unnamed: J30.12, J31.3
unnamed: J30.13, J31.2
unnamed: J30.14, J31.1
unnamed: J32.11, J33.4
unnamed: J32.12, J33.3
unnamed: J32.13, J33.2
unnamed: J32.14, J33.1
unnamed: J34.11, J35.4
unnamed: J34.12, J35.3
unnamed: J34.13, J35.2
unnamed: J34.14, J35.1
PUL1: J24.2; also elsewhere on the board
PUL2: J26.2; also elsewhere on the board
PUL3: J28.2; also elsewhere on the board
PUL4: J30.2; also elsewhere on the board
PUL5: J32.2; also elsewhere on the board
PUL6: J34.2; also elsewhere on the board
SELECT1: J24.5; also elsewhere on the board
SELECT2: J26.5; also elsewhere on the board
SELECT3: J28.5; also elsewhere on the board
SELECT4: J30.5; also elsewhere on the board
SELECT5: J32.5; also elsewhere on the board
SELECT6: J34.5; also elsewhere on the board
SPI1_MISO: J24.4, J26.4, J28.4, J30.4, J32.4, J34.4; also elsewhere on the board
SPI1_MOSI: J24.7, J26.7, J28.7, J30.7, J32.7, J34.7; also elsewhere on the board
SPI1_SCK: J24.6, J26.6, J28.6, J30.6, J32.6, J34.6; also elsewhere on the board

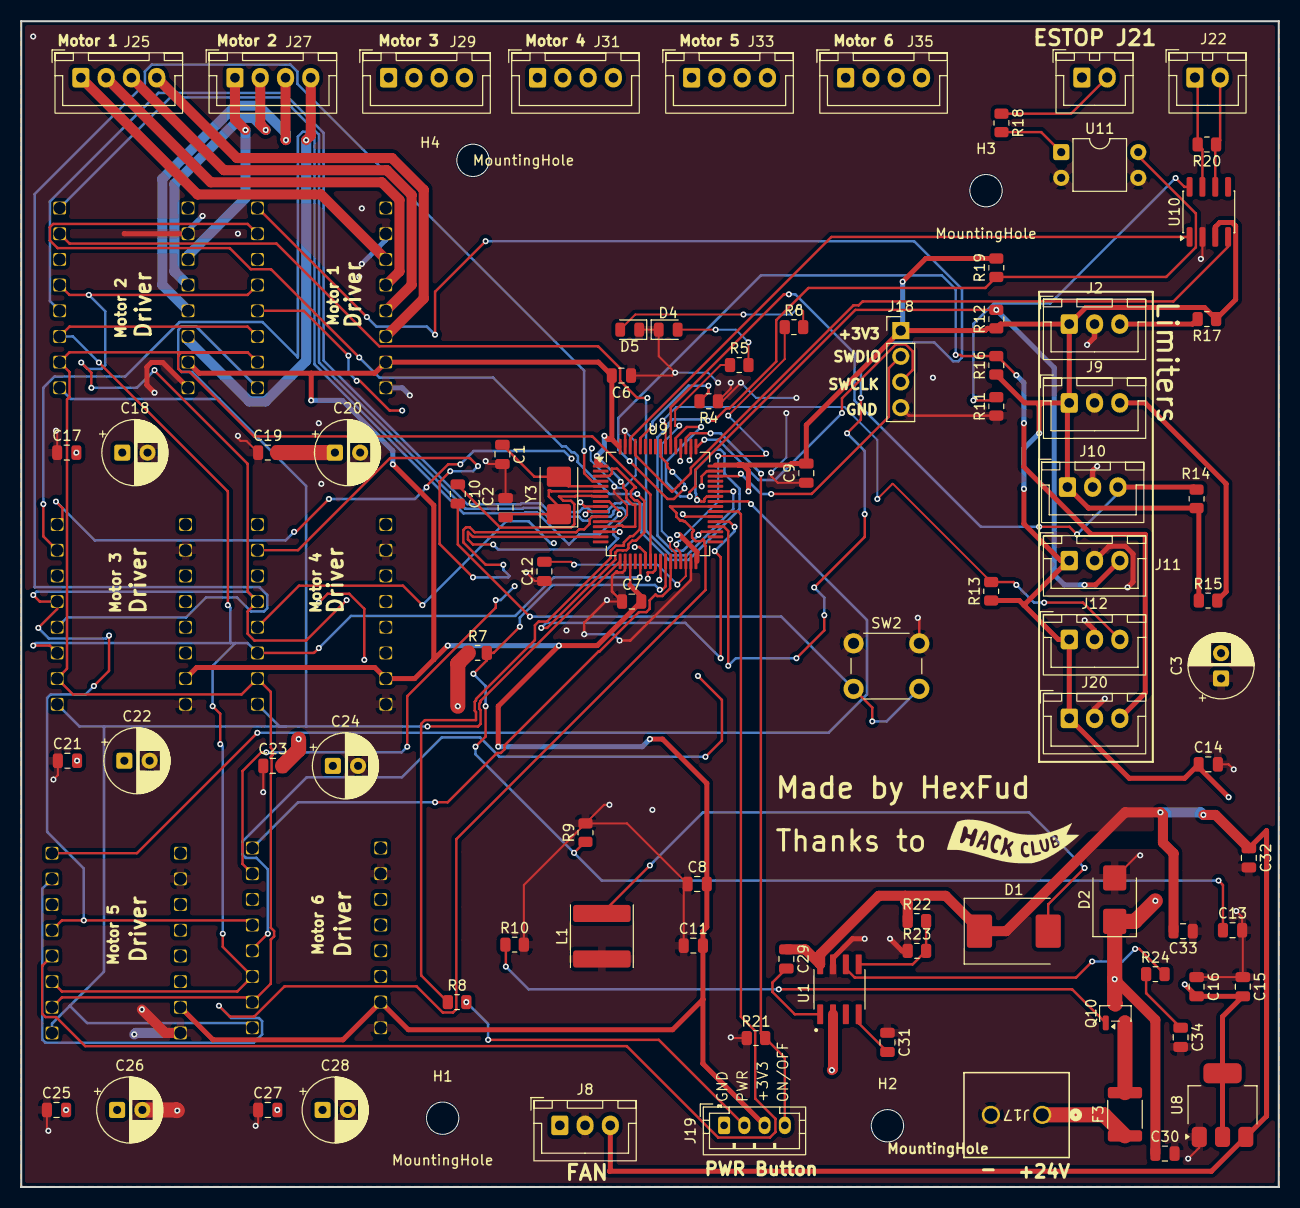
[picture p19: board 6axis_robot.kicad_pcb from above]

Board: 4 copper layers, 124.4 x 115.3 mm, 95 parts (0 on the bottom side), 89 nets.

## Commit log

2026-08-16 Add technical specifications for 6-axis robot controller
    Added detailed technical specifications for the 6-axis robot controller, including power supply, current ratings, thermal limits, and mechanical performance.
2026-08-16 Update firmware flashing instructions in README
    Added details about the J18 connector for ST-LINK V2 and included a link to STM32CubeProgrammer. Also added a connector pinout image.
2026-08-17 Revise README for clarity and safety information
    Updated the README to clarify PCB features, mechanical design choices, and safety advice.
2026-08-17 Update README with emergency stop and connections details
    Clarified emergency stop button functionality and added details about external connections.
2026-08-18 Added missing file
    [Arm_2.3mf, Arm_2_MS.3mf, PCB_Case_Lid.3mf]
2026-08-20 Added USD currency
    [Robot_BOM.xlsx]
2026-08-20 Replaced files
    [Arm_1.3mf, Arm_2.3mf, Arm_2_MS.3mf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]
